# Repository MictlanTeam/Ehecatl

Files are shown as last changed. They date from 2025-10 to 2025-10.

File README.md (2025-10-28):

# EHECATL - Line Follower Racing Robot





**EHECATL** (pronunciado "Ehécatl") es un robot seguidor de línea diseñado para competencias de racing. Su nombre proviene del dios azteca del viento, representando su característica principal: un sistema de succión mediante turbina para generar efecto ground y aumentar la tracción en curvas a alta velocidad.

## 🏆 Características Principales

### Hardware
- **Microcontrolador**: ESP32-S3-Zero
- **Sensores**: Array de 16 sensores IR con multiplexadores duales
- **Motores**: 2 motores DC con drivers RZ7886
- **Turbina**: Sistema de succión con ESC brushless (efecto ground)
- **Control**: Botón físico, señal externa de start, y comandos serial

### Software
- **Control PID**: Controlador proporcional-derivativo ajustable
- **Pre-inicio Inteligente**: Estabilización y activación de turbina antes del arranque
- **Aceleración Adaptativa**: Velocidad mínima de 20% para arranques rápidos
- **Protocolo ESC**: Control de turbina a 50Hz (protocolo servo estándar)
- **Lectura Simétrica**: Sensores leídos desde el centro hacia extremos
- **Calibración Automática**: Auto-calibración con umbral adaptativo

## 🛠️ Especificaciones Técnicas

### Mapa de Pines

| Componente | Pin | Tipo | Descripción |
|---|-----|---|---|
| **Motores** |
| Motor Izq A | 1 | PWM | Control motor izquierdo |
| Motor Izq B | 4 | PWM | Control motor izquierdo |
| Motor Der A | 9 | PWM | Control motor derecho |
| Motor Der B | 2 | PWM | Control motor derecho |
| **Sensores** |
| MUX_A | 3 | Digital Out | Control multiplexador (LSB) |
| MUX_B | 11 | Digital Out | Control multiplexador |
| MUX_C | 10 | Digital Out | Control multiplexador (MSB) |
| Sensores 1-8 | 8 | Analog In | Lectura multiplexador 1 |
| Sensores 9-16 | 7 | Analog In | Lectura multiplexador 2 |
| **Utilidades** |
| LED | 5 | Digital Out | LED de estado |
| Botón | 13 | Digital In | Botón con pull-up |
| Start Signal | 6 | Digital In | Señal de inicio externa |
| Turbina | 12 | PWM (ESC) | Control turbina/succión |

### Configuraciones PWM

#### Motores
- **Frecuencia**: 5 kHz
- **Resolución**: 10 bits (0-1023)
- **Canales**: 0-3

#### Turbina (ESC)
- **Frecuencia**: 50 Hz (protocolo servo)
- **Resolución**: 11 bits
- **Rango**: 102-204 (1000μs-2000μs)
- **Canal**: 4

### Parámetros PID

```cpp
KP = 0.2    // Ganancia proporcional
KD = 0.80   // Ganancia derivativa
```

### Tiempos de Control

- **Loop de control**: 1000 μs (1 kHz)
- **Timeout pérdida de línea**: 250 ms
- **Calibración sensores**: 3000 ms
- **Tiempo máximo de prueba**: 30000 ms

## ⚙️ Configuración

### Configuración de Flash (platformio.ini)

```ini
[env:esp32-s3-zero]
platform = espressif32
board = esp32-s3-devkitc-1
framework = arduino
board_build.mcu = esp32s3
board_build.f_cpu = 240000000L
board_build.flash_mode = qio
board_upload.flash_size = 4MB
board_build.arduino.memory_type = qio_opi
board_build.psram_type = opi
board_build.partitions = default.csv
monitor_speed = 115200
upload_speed = 921600
```

### Ajuste de Parámetros

Los parámetros principales se pueden ajustar en:

- **`control.h`**: Constantes PID, tiempos de control
- **`motors.h`**: Configuración PWM de motores y turbina
- **`sensors.h`**: Configuración de sensores

## 📱 Uso Básico

### Inicio del Robot

1. **Encendido**: Conectar alimentación
2. **Inicialización**: Esperar 2 segundos (ESC de turbina)
3. **Calibración**: Presionar botón → Mover robot sobre línea 3 segundos
4. **Listo**: LED indica que está listo para iniciar

### Modos de Inicio

El robot puede iniciarse de 3 formas:

1. **Botón Largo (>1s)**:
   - Presionar y mantener botón
   - Cuenta regresiva de 3 segundos
   - Último segundo: pre-inicio con turbina al 85%
   - ¡GO!

2. **Señal Externa (Pin 6)**:
   - Compatible con sistemas de competencia
   - Inicio inmediato al detectar HIGH en pin 6

3. **Comando Serial (`s`)**:
   - Enviar comando `s` por monitor serial
   - Cuenta regresiva de 3 segundos
   - Inicio automático

### Comandos Serial

| Comando | Función | Ejemplo |
|---|---|---|
| `s` | Iniciar carrera | - |
| `x` | Detener carrera | - |
| `r` | Mostrar sensores RAW | - |
| `c` | Mostrar sensores calibrados | - |
| `v[num]` | Cambiar velocidad base (0-100%) | `v40` |
| `a[num]` | Cambiar aceleración (0-100%) | `a70` |
| `f[num]` | Cambiar velocidad turbina (0-100%) | `f90` |
| `cal` | Re-calibrar sensores | - |

## 📊 Rendimiento

## 📝 Licencia

Este proyecto está bajo la Licencia MIT. Ver archivo `LICENSE` para más detalles.

## 🔗 Enlaces Útiles

- [Documentación ESP32-S3](https://docs.espressif.com/projects/esp-idf/en/latest/esp32s3/)
- [PlatformIO Docs](https://docs.platformio.org/)
- [ESP32-S3-Zero](https://www.waveshare.com/wiki/ESP32-S3-Zero)

---

**EHECATL** - El viento que domina la pista 💨🏎️

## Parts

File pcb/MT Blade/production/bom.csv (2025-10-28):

Designator | Footprint | Quantity | Value | LCSC Part #
AUX_FLEX1, FLEX_MORRO1 | TE_0-1734839-7_1x07-1MP_P0.5mm_Horizontal | 2 | Conn_01x07 | C388693
C1, C3 | 0805 | 2 | 10uF | C380331
C2, C4 | 0805 | 2 | 0.1uF | C2847428
MUX1, MUX2 | MUX_CD4051B | 2 | CD4051B | C3007951
R1, R10, R13, R16, R19, R22, R4, R7 | 0805 | 8 | 45 | C3017827
R11, R12, R14, R15, R17, R18, R2, R20, R21, R23, R24, R3, R5, R6, R8, R9 | 0805 | 16 | 10k | C17414
S1, S10, S11, S12, S13, S14, S15, S16, S2, S3, S4, S5, S6, S7, S8, S9 | ITR8307_SMD | 16 | ~ | C81632

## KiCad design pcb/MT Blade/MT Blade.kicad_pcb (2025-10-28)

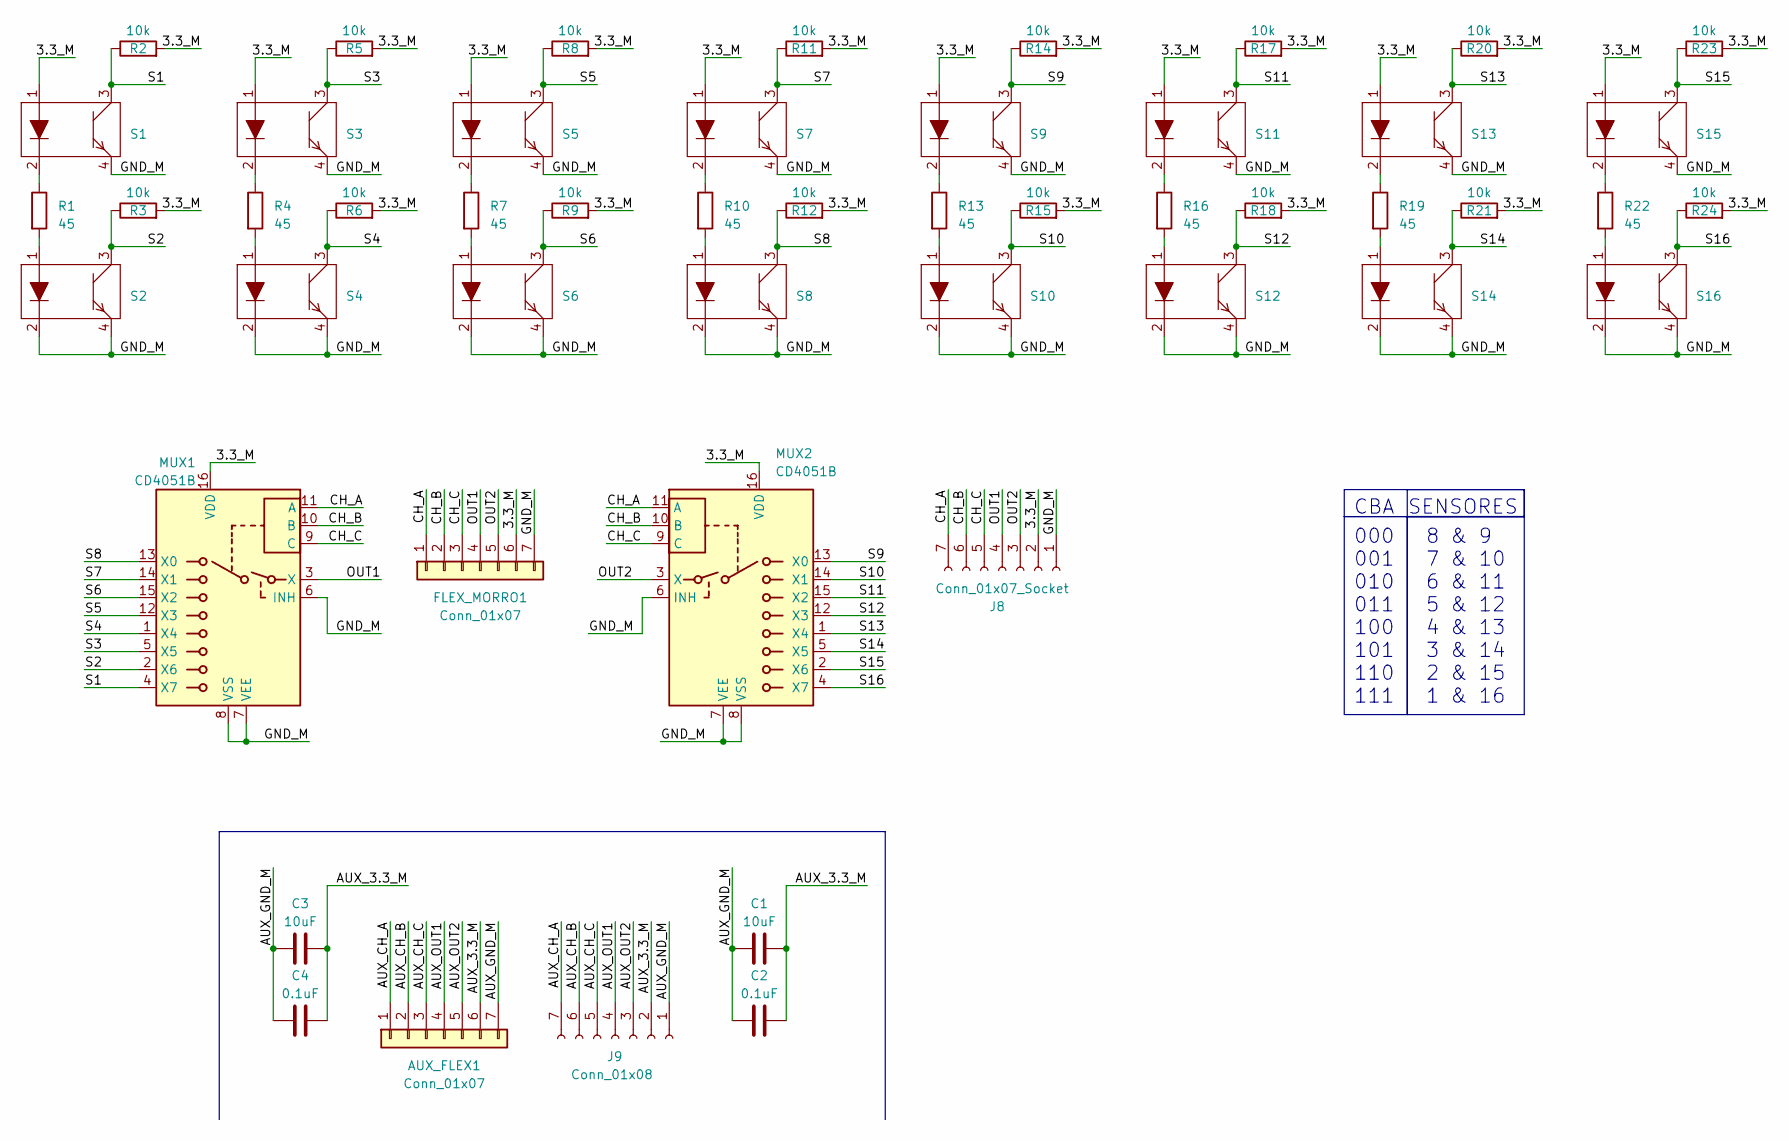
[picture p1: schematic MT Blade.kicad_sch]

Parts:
AUX_FLEX1: Conn_01x07; TE_0-1734839-7_1x07-1MP_P0.5mm_Horizontal; LCSC Part # C388693
C1, C3: 10uF; C_0805_2012Metric_Pad1.18x1.45mm_HandSolder; LCSC Part # C380331
C2, C4: 0.1uF; C_0805_2012Metric_Pad1.18x1.45mm_HandSolder; LCSC Part # C2847428
FLEX_MORRO1: Conn_01x07; TE_0-1734839-7_1x07-1MP_P0.5mm_Horizontal; LCSC Part # C388693
J8: Conn_01x07_Socket; PinHeader_1x07_P2.54mm_Vertical
J9: Conn_01x08; PinHeader_1x07_P2.54mm_Vertical
MUX1, MUX2: CD4051B; MUX_CD4051B; LCSC Part # C3007951
R1, R4, R7, R10, R13, R16, R19, R22: 45; R_0805_2012Metric_Pad1.20x1.40mm_HandSolder; LCSC Part # C3017827
R2, R3, R5, R6, R8, R9, R11, R12, R14, R15, R17, R18, R20, R21, R23, R24: 10k; R_0805_2012Metric_Pad1.20x1.40mm_HandSolder; LCSC Part # C17414
S1, S2, S3, S4, S5, S6, S7, S8, S9, S10, S11, S12, S13, S14, S15, S16: ITR8307_SMD; LCSC Part # C81632

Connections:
/3.3_M: FLEX_MORRO1.6, J8.2, MUX1.16 (VDD), MUX2.16 (VDD), R2.2, R3.2, R5.2, R6.2, R8.2, R9.2, R11.2, R12.2, R14.2, R15.2, R17.2, R18.2, R20.2, R21.2, R23.2, R24.2, S1.1, S3.1, S5.1, S7.1, S9.1, S11.1, S13.1, S15.1
/AUX_3.3_M: AUX_FLEX1.6, C1.1, C2.1, C3.1, C4.1, J9.2
/AUX_CH_A: AUX_FLEX1.1, J9.7
/AUX_CH_B: AUX_FLEX1.2, J9.6
/AUX_CH_C: AUX_FLEX1.3, J9.5
/AUX_GND_M: AUX_FLEX1.7, C1.2, C2.2, C3.2, C4.2, J9.1
/AUX_OUT1: AUX_FLEX1.4, J9.4
/AUX_OUT2: AUX_FLEX1.5, J9.3
/CH_A: FLEX_MORRO1.1, J8.7, MUX1.11 (A), MUX2.11 (A)
/CH_B: FLEX_MORRO1.2, J8.6, MUX1.10 (B), MUX2.10 (B)
/CH_C: FLEX_MORRO1.3, J8.5, MUX1.9 (C), MUX2.9 (C)
/GND_M: FLEX_MORRO1.7, J8.1, MUX1.6 (INH), MUX1.7 (VEE), MUX1.8 (VSS), MUX2.6 (INH), MUX2.7 (VEE), MUX2.8 (VSS), S1.4, S2.2, S2.4, S3.4, S4.2, S4.4, S5.4, S6.2, S6.4, S7.4, S8.2, S8.4, S9.4, S10.2, S10.4, S11.4, S12.2, S12.4, S13.4, S14.2, S14.4, S15.4, S16.2, S16.4
/OUT1: FLEX_MORRO1.4, J8.4, MUX1.3 (X)
/OUT2: FLEX_MORRO1.5, J8.3, MUX2.3 (X)
/S1: MUX1.4 (X7), R2.1, S1.3
/S2: MUX1.2 (X6), R3.1, S2.3
/S3: MUX1.5 (X5), R5.1, S3.3
/S4: MUX1.1 (X4), R6.1, S4.3
/S5: MUX1.12 (X3), R8.1, S5.3
/S6: MUX1.15 (X2), R9.1, S6.3
/S7: MUX1.14 (X1), R11.1, S7.3
/S8: MUX1.13 (X0), R12.1, S8.3
/S9: MUX2.13 (X0), R14.1, S9.3
/S10: MUX2.14 (X1), R15.1, S10.3
/S11: MUX2.15 (X2), R17.1, S11.3
/S12: MUX2.12 (X3), R18.1, S12.3
/S13: MUX2.1 (X4), R20.1, S13.3
/S14: MUX2.5 (X5), R21.1, S14.3
/S15: MUX2.2 (X6), R23.1, S15.3
/S16: MUX2.4 (X7), R24.1, S16.3
unnamed: R1.1, S1.2
unnamed: R1.2, S2.1
unnamed: R4.1, S3.2
unnamed: R4.2, S4.1
unnamed: R7.1, S5.2
unnamed: R7.2, S6.1
unnamed: R10.1, S7.2
unnamed: R10.2, S8.1
unnamed: R13.1, S9.2
unnamed: R13.2, S10.1
unnamed: R16.1, S11.2
unnamed: R16.2, S12.1
unnamed: R19.1, S13.2
unnamed: R19.2, S14.1
unnamed: R22.1, S15.2
unnamed: R22.2, S16.1

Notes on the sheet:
CBA
SENSORES
8 & 9 7 & 10 6 & 11 5 & 12 4 & 13 3 & 14 2 & 15 1 & 16
000 001 010 011 100 101 110 111

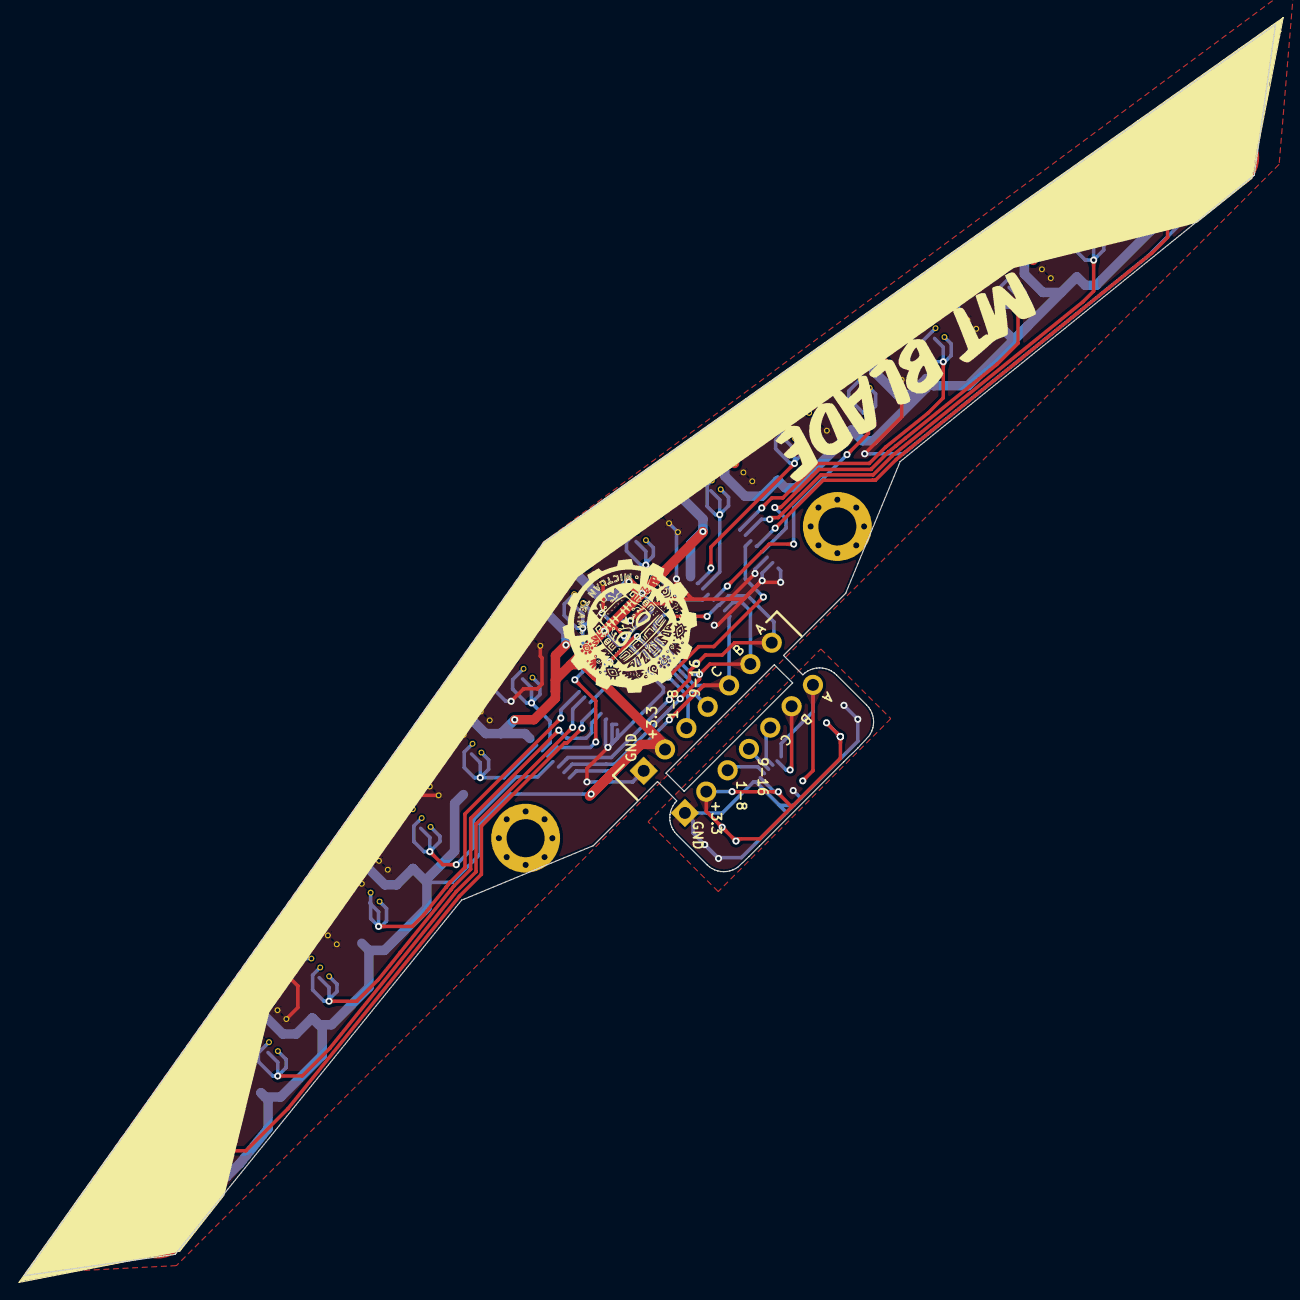
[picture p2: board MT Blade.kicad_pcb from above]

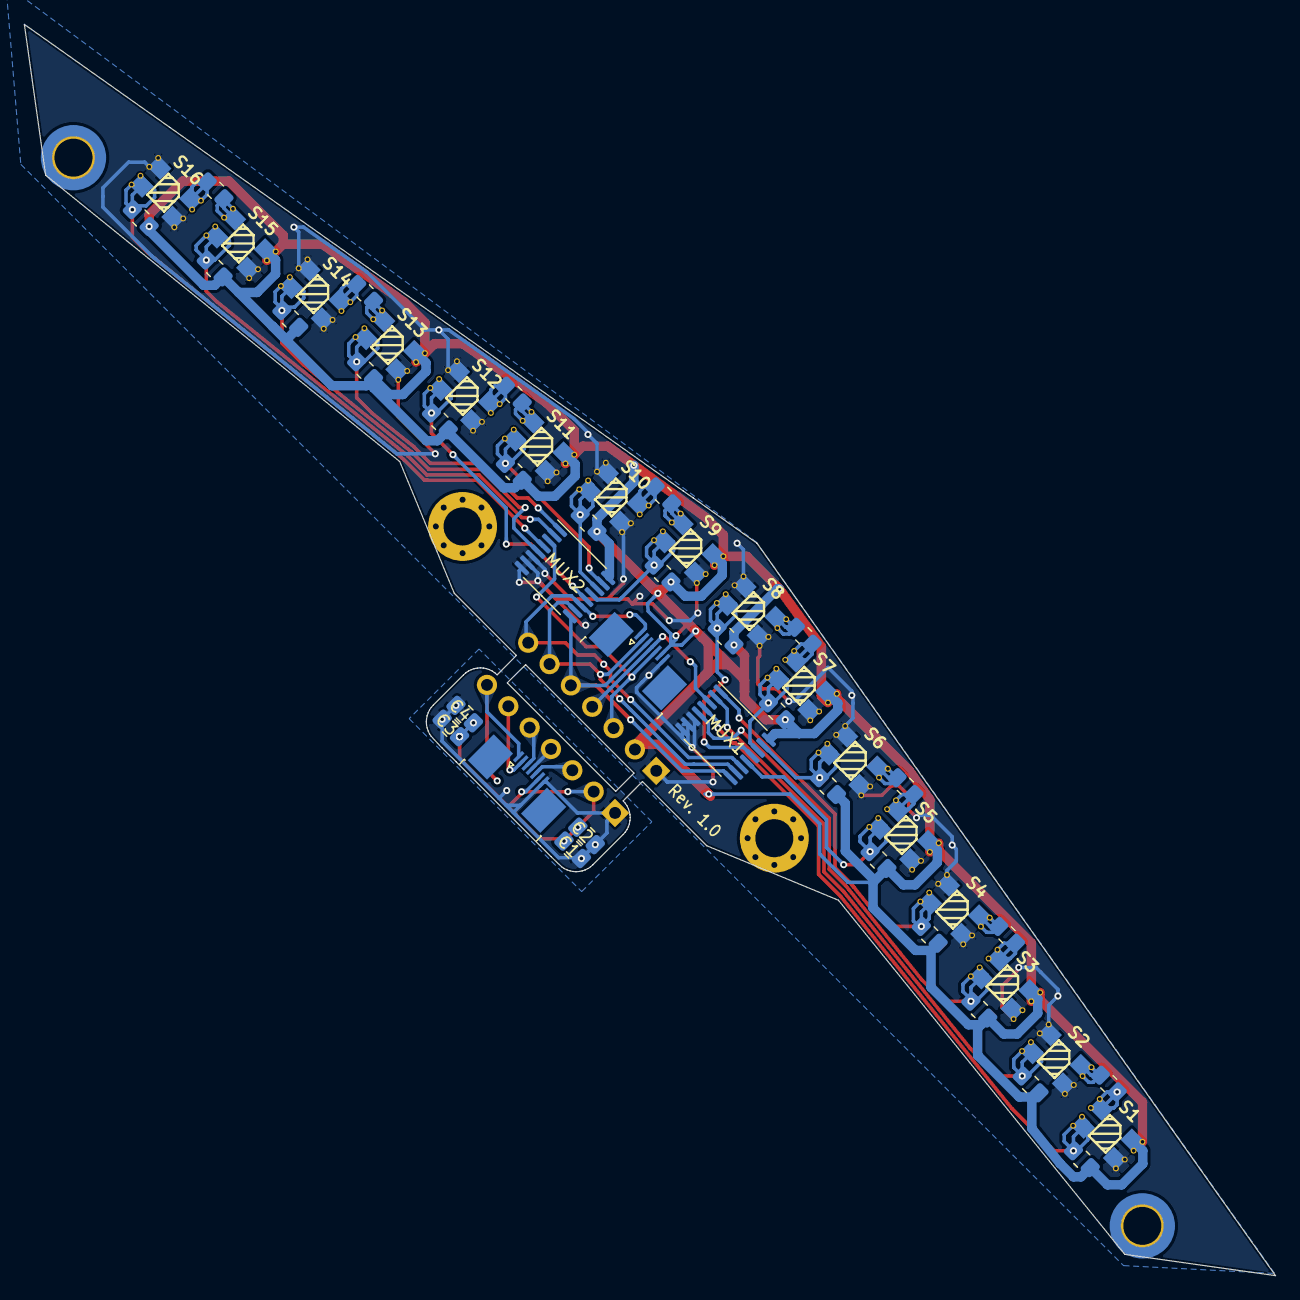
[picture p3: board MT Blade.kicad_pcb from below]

Board: 2 copper layers, 105.3 x 105.3 mm, 51 parts (49 on the bottom side), 46 nets.

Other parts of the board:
G: LOGO; MT_Silkscreen 10mm

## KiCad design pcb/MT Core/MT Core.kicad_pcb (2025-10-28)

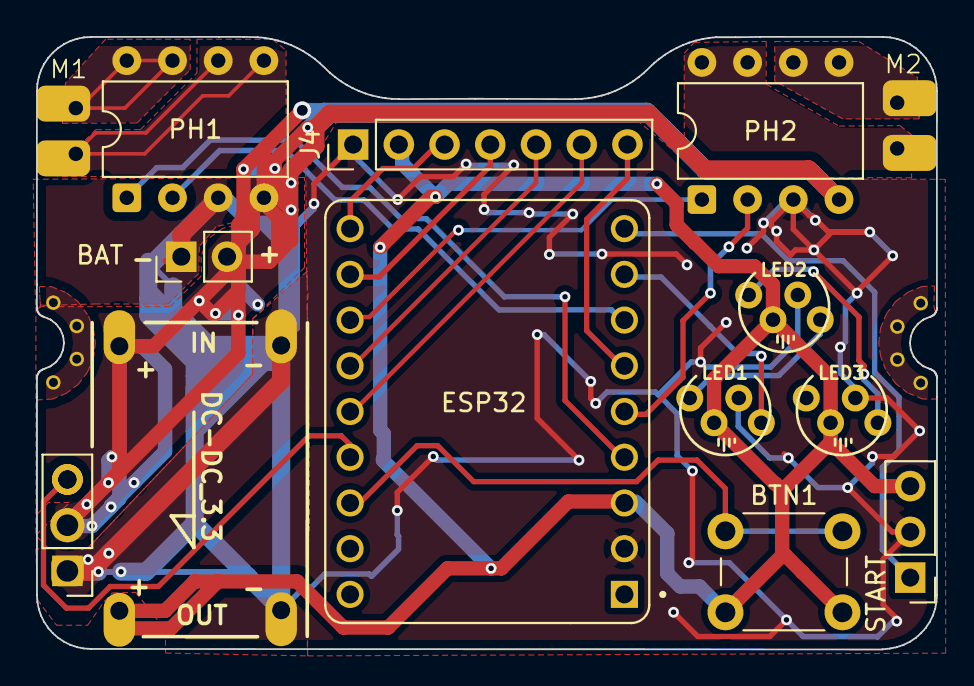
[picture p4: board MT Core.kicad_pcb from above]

Board: 2 copper layers, 50.0 x 34.0 mm, 15 parts (0 on the bottom side), 22 nets.

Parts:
BAT: Conn_01x02_Socket; PinHeader_1x02_P2.54mm_Vertical
BTN1: SW_PUSH_6mm_H4.3mm
DC-DC_3.3: DC-DC_3.3 CN3903
ESP32: ESP32-S3-ZERO
J1: Conn_01x03_Socket; PinHeader_1x03_P2.54mm_Vertical
J4: Conn_01x07_Socket; PinHeader_1x07_P2.54mm_Vertical
LED1, LED2, LED3: LED_D5.0mm-4_RGB_Staggered_Pins
M1, M2: Conn_01x02_Socket; motor_pads
PH1, PH2: DIP-8_W7.62mm
START: Conn_01x03_Socket; PinHeader_1x03_P2.54mm_Vertical
SUCC: Conn_01x03_Socket; PinHeader_1x03_P2.54mm_Vertical

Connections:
+3.3V: BTN1.2, DC-DC_3.3.3 (OUT+), ESP32.3V3 (3V3(OUT)), J4.2, LED1.2 (VDD), LED2.2 (VDD), LED3.2 (VDD), START.3
/BATT: BAT.2, DC-DC_3.3.1 (IN+), J1.2, PH1.4 (VCC), PH2.4 (VCC), SUCC.2
/BTN: BTN1.1, ESP32.13 (GP13)
/LEDS: ESP32.5 (GP5), LED1.4 (DIN)
/PIN0: ESP32.7 (GP7), J4.3
/PIN1: ESP32.8 (GP8), J4.4
/PIN3: ESP32.10 (GP10), J4.5
/PIN4: ESP32.11 (GP11), J4.6
/PIN9: ESP32.3 (GP3), J4.7
/PWM_M1A: ESP32.1 (GP1), PH1.1 (S1)
/PWM_M1B: ESP32.4 (GP4), PH1.2 (S2)
/PWM_M2A: ESP32.9 (GP9), PH2.1 (S1)
/PWM_M2B: ESP32.2 (GP2), PH2.2 (S2)
/START: ESP32.6 (GP6), START.1
/SUCC: ESP32.12 (GP12), J1.3, SUCC.3
GND: BAT.1, DC-DC_3.3.2 (IN-), DC-DC_3.3.4 (OUT-), ESP32.GND, J1.1, J4.1, LED1.3 (GND), LED2.3 (GND), LED3.3 (GND), PH1.3 (GND), PH2.3 (GND), START.2, SUCC.1
unnamed: LED1.1 (DOUT), LED2.4 (DIN)
unnamed: LED2.1 (DOUT), LED3.4 (DIN)
unnamed: M1.1, PH1.5 (M+), PH1.6 (M+)
unnamed: M1.2, PH1.7 (M-), PH1.8 (M-)
unnamed: M2.1, PH2.5 (M+), PH2.6 (M+)
unnamed: M2.2, PH2.7 (M-), PH2.8 (M-)

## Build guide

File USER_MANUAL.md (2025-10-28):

# 📖 Manual de Usuario - EHECATL

## Guía de Operación del Robot Seguidor de Línea

---

## 🚦 Inicio Rápido

### 1. Primera Vez - Configuración Inicial

#### Paso 1: Conexión
1. Conecta la batería al robot
2. Espera 2 segundos (oirás un beep del ESC de la turbina)
3. El LED parpadeará indicando que está listo para calibrar

#### Paso 2: Calibración de Sensores
1. **Presiona el botón** del robot
2. **Mueve el robot lentamente** sobre la línea durante 3 segundos
   - Pasa por línea negra
   - Pasa por fondo blanco
   - Repite varias veces
3. Cuando termine:
   - ✅ LED se encenderá brevemente si calibración OK
   - ❌ LED parpadeará rápido si falló (repetir calibración)

> **💡 Consejo**: Mueve el robot lentamente y asegúrate de que todos los sensores pasen por la línea

---

## 🏁 Usar el Robot

### Método 1: Botón Físico (Recomendado)

1. **Posiciona** el robot en la pista (centrado en la línea)
2. **Presiona y mantén** el botón por más de 1 segundo
3. **Suelta** el botón cuando el LED parpadee rápido
4. **Cuenta regresiva automática**:
   ```
   3... (LED parpadea)
   2... (LED parpadea)
   1... (LED encendido fijo - turbina al 85%)
   ¡GO! (Robot arranca)
   ```

5. El robot seguirá la línea automáticamente
6. Se detendrá solo después de 30 segundos

### Método 2: Señal Externa (Para Competencias)

1. Conecta sistema de inicio al **Pin 6**
2. Cuando el pin reciba señal HIGH, el robot arranca inmediatamente
3. No hay cuenta regresiva en este modo

### Método 3: Comando Serial (Para Pruebas)

1. Abre el monitor serial (115200 baud)
2. Escribe: `s` y presiona Enter
3. Cuenta regresiva de 3 segundos
4. Robot arranca automáticamente

---

## 🛑 Detener el Robot

### Durante la Carrera:

- **Botón**: Presiona brevemente el botón
- **Serial**: Envía comando `x`
- **Automático**: Robot se detiene si pierde la línea por más de 250ms

---

## ⚙️ Ajustar Configuración

### Abrir Monitor Serial

**En PlatformIO**:
- Click en icono "Monitor Serial"
- O presiona `Ctrl+Alt+M`

**Velocidad**: 115200 baud

### Comandos Disponibles

#### Velocidad del Robot
```
v30   → Velocidad base 30%
v50   → Velocidad base 50%
v80   → Velocidad base 80%
```

#### Aceleración
```
a40   → Aceleración lenta
a60   → Aceleración media (recomendada)
a80   → Aceleración rápida
```

#### Turbina
```
f0    → Turbina apagada
f50   → Turbina 50%
f80   → Turbina 80% (recomendada)
f100  → Turbina máxima
```

#### Otros Comandos
```
s     → Iniciar carrera
x     → Detener carrera
r     → Ver valores RAW de sensores
c     → Ver sensores calibrados (0 o 1)
cal   → Re-calibrar sensores
```

---

## 🎯 Configuraciones Recomendadas

### Para Empezar (Pista Desconocida)
```
v30    (velocidad baja)
a60    (aceleración media)
f60    (turbina media)
```

### Pista con Curvas Suaves
```
v50    (velocidad media)
a70    (aceleración alta)
f80    (turbina alta)
```

### Pista Rápida con Pocas Curvas
```
v70    (velocidad alta)
a80    (aceleración muy alta)
f80    (turbina alta)
```

### Modo Máximo (Solo Pistas Conocidas)
```
v100   (velocidad máxima)
a90    (aceleración máxima)
f100   (turbina máxima)
```

---

## 🔧 Mantenimiento

### Antes de Cada Carrera

1. ✅ **Verificar batería cargada**
2. ✅ **Limpiar sensores** (paño seco suave)
3. ✅ **Verificar ruedas** (no hay objetos pegados)
4. ✅ **Probar turbina** (debe girar suave al encender)
5. ✅ **Calibrar sensores** si cambió la pista

### Después de Cada Carrera

1. ✅ **Desconectar batería**
2. ✅ **Limpiar robot** (quitar polvo)
3. ✅ **Revisar tornillos** (que estén ajustados)

### Limpieza de Sensores

**Frecuencia**: Cada 5 carreras o si detectas problemas

**Método**:
1. Apaga el robot
2. Usa paño de microfibra seco
3. Limpia suavemente cada sensor
4. NO uses líquidos
5. NO presiones fuerte

---

## 🐛 Solución de Problemas Comunes

### Problema: Robot no enciende

**Posibles causas**:
- ❌ Batería descargada
- ❌ Conexión suelta

**Solución**:
1. Verifica voltaje de batería (mínimo 7.4V)
2. Revisa conexiones de alimentación

---

### Problema: Robot pierde la línea constantemente

**Posibles causas**:
- ❌ Sensores sucios
- ❌ Mala calibración
- ❌ Velocidad muy alta

**Solución**:
1. Limpia sensores con paño seco
2. Re-calibra: Comando `cal`
3. Reduce velocidad: `v30`
4. Verifica en serial: Comando `r` para ver valores

---

### Problema: Turbina no funciona

**Posibles causas**:
- ❌ ESC no inicializado
- ❌ Turbina configurada en 0%

**Solución**:
1. Espera 2-3 segundos al encender (beep del ESC)
2. Configura turbina: `f80`
3. Verifica conexión del ESC

---

### Problema: Motores no responden

**Posibles causas**:
- ❌ Robot no está en modo carrera
- ❌ Conexión suelta
- ❌ Driver sobrecalentado

**Solución**:
1. Inicia carrera: Botón largo o comando `s`
2. Verifica conexiones de motores
3. Si drivers están calientes, espera 5 minutos

---

### Problema: Robot gira en círculos

**Posibles causas**:
- ❌ Mal montaje de ruedas
- ❌ Motores invertidos
- ❌ Calibración incorrecta

**Solución**:
1. Verifica que ambas ruedas giren bien
2. Re-calibra sensores
3. Prueba en pista simple primero

---

### Problema: Sensores no detectan línea

**Verificación**:
1. Comando `r` en serial
2. Valores deben cambiar al pasar sobre línea:
   - Fondo blanco: ~3000-4000
   - Línea negra: ~100-500
3. Si no cambian:
   - Sensores muy altos/bajos de la pista
   - Sensores sucios
   - Luz ambiental muy intensa

**Solución**:
1. Ajusta altura del robot (3-5mm ideal)
2. Limpia sensores
3. Evita luz solar directa
4. Re-calibra

---

## 📊 Interpretación de Sensores

### Ver Estado de Sensores

Comando `c` muestra sensores calibrados:
```
CAL: 0 0 0 0 0 1 1 1 1 0 0 0 0 0 0 0
     ◄────────────────────────────►
     Izq                         Der
```

**Interpretación**:
- `1` = Sensor detecta línea (negro)
- `0` = Sensor detecta fondo (blanco)

**Ejemplos**:

```
Línea Centrada:
0 0 0 0 0 0 1 1 1 0 0 0 0 0 0 0
              ▲▲▲
           Centro perfecto
```

```
Línea a la Derecha:
0 0 0 0 0 0 0 0 0 0 1 1 1 0 0 0
                        ▲▲▲
                  Debe girar derecha
```

```
Línea a la Izquierda:
0 0 1 1 1 0 0 0 0 0 0 0 0 0 0 0
      ▲▲▲
  Debe girar izquierda
```

```
Línea Perdida:
0 0 0 0 0 0 0 0 0 0 0 0 0 0 0 0
          ⚠️ ALERTA ⚠️
```

---

## 💾 Guardar Configuración

El robot **NO guarda** configuraciones automáticamente.

Para guardar tus configuraciones preferidas:

### Opción 1: Modificar Código
En `main.cpp` líneas 70-72:
```cpp
set_base_speed(50);        // Cambia 50 por tu velocidad
set_base_accel_speed(70);  // Cambia 70 por tu aceleración
set_base_fan_speed(80);    // Cambia 80 por tu turbina
```

### Opción 2: Crear Script
Crea archivo `config.txt` con tus comandos:
```
v50
a70
f80
```
Y envíalos cada vez que enciendas

---

## 🔋 Batería

### Especificaciones
- **Voltaje**: 7.4V - 11.1V (2S - 3S LiPo)
- **Capacidad recomendada**: 1000-2000 mAh
- **Descarga**: 20C o superior

### Duración Estimada
- **Sin turbina**: ~15-20 minutos
- **Con turbina 50%**: ~8-12 minutos
- **Con turbina 100%**: ~5-8 minutos

### Indicadores de Batería Baja
- Robot pierde potencia en curvas
- Turbina hace ruidos extraños
- Velocidad máxima reducida

**⚠️ IMPORTANTE**:
- Nunca descargues LiPo por debajo de 3.0V por celda
- Usa alarma de voltaje o cargador con balance

---

## 🎓 Consejos de Competencia

### Antes de la Competencia

1. **Practica en pista similar**
2. **Calibra con la pista real** de competencia
3. **Prueba diferentes configuraciones**
4. **Anota tus mejores configuraciones**
5. **Carga batería completa**
6. **Lleva baterías de repuesto**

### Durante Clasificación

1. **Primera vuelta: Conservador** (v40, a50, f60)
2. **Observa el circuito** mientras el robot corre
3. **Identifica curvas difíciles**
4. **Ajusta configuración** basado en observación

### Para la Final

1. **Usa configuración probada**
2. **No cambies a último momento**
3. **Calibra 5 minutos antes de tu turno**
4. **Verifica batería cargada**

---

## 📈 Mejorando Tiempos

### Progresión Sugerida

**Semana 1**: Conocer el robot
```
v30, a50, f50
Objetivo: Completar pista sin salirse
```

**Semana 2**: Aumentar confianza
```
v50, a60, f70
Objetivo: Completar pista consistentemente
```

**Semana 3**: Velocidad
```
v70, a70, f80
Objetivo: Reducir tiempo en 30%
```

**Semana 4+**: Optimización
```
v80-100, a80-90, f80-100
Objetivo: Tiempo mínimo consistente
```

---

## ✅ Checklist Pre-Carrera

Antes de cada carrera, verifica:

- [ ] Batería cargada (>7.4V)
- [ ] Sensores limpios
- [ ] Turbina funciona (oyes el beep al encender)
- [ ] LED responde al presionar botón
- [ ] Calibración reciente (<10 minutos)
- [ ] Configuración cargada (v, a, f)
- [ ] Robot centrado en línea de inicio
- [ ] Ruedas limpias (sin objetos)
- [ ] Tornillos ajustados

---

## 🎉 ¡Listo para Competir!

Ahora que conoces tu robot EHECATL, es momento de dominarlo en la pista.

**Recuerda**:
- Empieza lento y aumenta velocidad gradualmente
- La calibración es CRÍTICA
- Cada pista es diferente
- Práctica hace al maestro

---

**¡Buena suerte en tus carreras!** 🏁💨

*EHECATL - El viento que domina la pista*

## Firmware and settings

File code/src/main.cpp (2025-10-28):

#include <Arduino.h>
#include <pinout.h>
#include <sensors.h>
#include <motors.h>
#include <control.h>
#include <utils.h>

/**
 * @brief Configuración del robot
 *
 */
#define TEST_DURATION_MS 30000   // Tiempo máximo de prueba: 30 segundos
#define START_DELAY_MS 3000      // Delay antes de iniciar: 3 segundos

void setup() {
  Serial.begin(115200);
  delay(1000);

  Serial.println("==============================================");
  Serial.println("  EHECATL - Line Follower Robot");
  Serial.println("  Basado en PX-01 Basic");
  Serial.println("==============================================");
  Serial.println();

  // Inicializar componentes
  Serial.println("Inicializando componentes...");
  init_utils();
  init_sensors();
  init_motors();

  Serial.println();
  Serial.println("==============================================");
  Serial.println("  CONFIGURACION DE PINES");
  Serial.println("==============================================");
  Serial.println("Motor Izquierdo:");
  Serial.println("  PWMA: Pin 1");
  Serial.println("  PWMB: Pin 4");
  Serial.println();
  Serial.println("Motor Derecho:");
  Serial.println("  PWMA: Pin 9");
  Serial.println("  PWMB: Pin 2");
  Serial.println();
  Serial.println("Sensores (Multiplexadores):");
  Serial.println("  MUX_A: Pin 3");
  Serial.println("  MUX_B: Pin 11");
  Serial.println("  MUX_C: Pin 10");
  Serial.println("  Lectura 1-8:  Pin 8");
  Serial.println("  Lectura 9-16: Pin 7");
  Serial.println();
  Serial.println("Utilidades:");
  Serial.println("  LED:     Pin 5");
  Serial.println("  Boton:   Pin 13");
  Serial.println("  Start:   Pin 6");
  Serial.println("  Turbina: Pin 12");
  Serial.println("==============================================");
  Serial.println();

  // LED parpadeando indicando calibración
  Serial.println("Presiona el boton para calibrar sensores...");
  while (get_btn_state() != BTN_PRESSED && get_btn_state() != BTN_LONG_PRESSED) {
    blink_led(500);
  }
  set_led(false);
  delay(500);

  // Calibrar sensores
  calibrate_sensors();

  // Configurar velocidades
  set_base_speed(30);        // Velocidad base: 30%
  set_base_accel_speed(60);  // Aceleración: 60%
  set_base_fan_speed(80);    // Turbina: 80%

  Serial.println("Sistema listo!");
  Serial.println();
  Serial.println("==============================================");
  Serial.println("  MODOS DE INICIO");
  Serial.println("==============================================");
  Serial.println("  1. Presion LARGA del boton (>1s)");
  Serial.println("  2. Senal de START (Pin 6)");
  Serial.println("  3. Comando serial: s");
  Serial.println();
  Serial.println("  OTROS COMANDOS:");
  Serial.println("  x - Detener carrera");
  Serial.println("  r - Mostrar sensores RAW");
  Serial.println("  c - Mostrar sensores calibrados");
  Serial.println("  v[num] - Cambiar velocidad base (ej: v40)");
  Serial.println("  a[num] - Cambiar aceleracion (ej: a70)");
  Serial.println("  f[num] - Cambiar velocidad turbina (ej: f90)");
  Serial.println("  cal - Re-calibrar sensores");
  Serial.println("==============================================");
  Serial.println();

  // LED indicando listo para iniciar
  set_led(true);
  delay(500);
  set_led(false);
}

void loop() {
  // Verificar si NO está en carrera
  if (!is_race_started()) {

    // Leer estado del botón
    BTN_STATES btn_state = get_btn_state();

    // Mientras el botón está presionado, parpadear LED rápido
    if (btn_state == BTN_PRESSING && get_btn_pressing_ms() >= 250) {
      blink_led(125);
    }

    // Si se soltó el botón después de presión larga, iniciar carrera
    if (btn_state == BTN_LONG_PRESSED) {
      Serial.println();
      Serial.println("Boton LARGO detectado!");
      set_led(true);

      // Cuenta regresiva con parpadeos (3 segundos)
      Serial.println("Iniciando en:");
      long starting_ms = millis();
      long countdown_duration = 3000;  // 3 segundos

      while (millis() < (starting_ms + countdown_duration)) {
        long elapsed = millis() - starting_ms;

        // Primeros 2 segundos: parpadeo lento
        if (elapsed < countdown_duration - 1000) {
          // Mostrar cuenta regresiva
          int seconds_remaining = 3 - (elapsed / 1000);
          static int last_second = -1;
          if (seconds_remaining != last_second) {
            Serial.print("  ");
            Serial.print(seconds_remaining);
            Serial.println("...");
            last_second = seconds_remaining;
          }

          // Parpadeo cada 500ms
          if ((elapsed % 1000) < 500) {
            set_led(true);
          } else {
            set_led(false);
          }

        } else {
          // Último segundo: PRE-INICIO INTELIGENTE
          set_led(true);
          set_race_starting(true);

          // Activar turbina al 85% para preparar succión
          if (get_base_fan_speed() > 0) {
            set_fan_speed(get_base_fan_speed() * 0.85f);
            Serial.println("  Pre-inicio: Turbina activada al 85%");
          }

          // Ejecutar control PID sin avanzar (mantiene centrado)
          initial_control_loop();
        }
      }

      Serial.println("  GO!");
      set_led(false);
      set_race_started(true);
    }

    // Verificar señal de START externa
    if (get_start_signal()) {
      Serial.println();
      Serial.println("Senal de START detectada!");
      delay(100);  // Pequeño delay para estabilizar
      set_race_started(true);
    }

    // Procesar comandos del serial
    if (Serial.available() > 0) {
      String command = Serial.readStringUntil('\n');
      command.trim();

      if (command == "s") {
        // Iniciar carrera con delay
        Serial.println();
        Serial.println("Iniciando en 3 segundos...");
        for (int i = 3; i > 0; i--) {
          Serial.print(i);
          Serial.println("...");
          delay(1000);
        }
        set_race_started(true);

      } else if (command == "r") {
        // Mostrar sensores RAW
        print_sensors_raw();

      } else if (command == "c") {
        // Mostrar sensores calibrados
        print_sensors_calibrated();

      } else if (command.startsWith("v")) {
        // Cambiar velocidad base
        int speed = command.substring(1).toInt();
        set_base_speed(speed);

      } else if (command.startsWith("a")) {
        // Cambiar aceleración
        int accel = command.substring(1).toInt();
        set_base_accel_speed(accel);

      } else if (command.startsWith("f")) {
        // Cambiar velocidad turbina
        int fan = command.substring(1).toInt();
        set_base_fan_speed(fan);

      } else if (command == "cal") {
        // Re-calibrar sensores
        Serial.println("Re-calibrando sensores...");
        calibrate_sensors();

      } else if (command == "x") {
        // Este comando solo funciona durante la carrera
        Serial.println("El robot no esta en carrera");

      } else {
        Serial.println("Comando no reconocido");
      }
    }

  } else {
    // EN CARRERA

    // Ejecutar bucle de control
    control_loop();

    // Verificar comando de detención por serial
    if (Serial.available() > 0) {
      String command = Serial.readStringUntil('\n');
      command.trim();
      if (command == "x") {
        Serial.println();
        Serial.println("Detencion manual solicitada");
        set_race_started(false);
      }
    }

    // Verificar botón para detener
    BTN_STATES btn_state = get_btn_state();
    if (btn_state == BTN_PRESSED || btn_state == BTN_LONG_PRESSED) {
      Serial.println();
      Serial.println("Boton presionado - Deteniendo");
      set_race_started(false);
    }

    // Detener después del tiempo máximo de prueba
    if (millis() - get_race_started_ms() >= TEST_DURATION_MS) {
      Serial.println();
      Serial.println("Tiempo de prueba completado");
      set_race_started(false);
    }
  }
}

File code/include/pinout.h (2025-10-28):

#ifndef PINOUT_H
#define PINOUT_H

/**
 * @brief Pin del LED de estado
 *
 */
#define LED_PIN 5

/**
 * @brief Pin del botón de inicio
 *
 */
#define BUTTON_PIN 13

/**
 * @brief Pin de la señal de start (entrada)
 *
 */
#define START_SIGNAL_PIN 6

/**
 * @brief Pin de control de la turbina/succión
 *
 */
#define FAN_PIN 12

/**
 * @brief Pines de control de multiplexadores (compartidos)
 *
 */
#define MUX_A 3
#define MUX_B 11
#define MUX_C 10

/**
 * @brief Pines de lectura de sensores
 *
 */
#define SENSOR_1_8 8    // Lee sensores 1-8
#define SENSOR_9_16 7   // Lee sensores 9-16

/**
 * @brief Pines del driver RZ7886 - Motor Izquierdo
 *
 */
#define MOTOR_LEFT_A 1
#define MOTOR_LEFT_B 4

/**
 * @brief Pines del driver RZ7886 - Motor Derecho
 *
 */
#define MOTOR_RIGHT_A 9
#define MOTOR_RIGHT_B 2

#endif // PINOUT_H

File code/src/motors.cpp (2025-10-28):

#include <motors.h>
#include <control.h>

/**
 * @brief Inicializa los motores configurando los canales PWM
 *
 */
void init_motors() {
  // Configuración de los canales PWM del Timer - Motores
  ledcSetup(PWM_MOTOR_LEFT_A, PWM_MOTORS_HZ, PWM_MOTORS_RESOLUTION);
  ledcSetup(PWM_MOTOR_LEFT_B, PWM_MOTORS_HZ, PWM_MOTORS_RESOLUTION);
  ledcSetup(PWM_MOTOR_RIGHT_A, PWM_MOTORS_HZ, PWM_MOTORS_RESOLUTION);
  ledcSetup(PWM_MOTOR_RIGHT_B, PWM_MOTORS_HZ, PWM_MOTORS_RESOLUTION);

  // Configuración del canal PWM para ESC de turbina (50Hz = protocolo servo)
  ledcSetup(PWM_FAN, PWM_FAN_HZ, PWM_FAN_RESOLUTION);

  // Asignación de los pines a los canales PWM
  ledcAttachPin(MOTOR_LEFT_A, PWM_MOTOR_LEFT_A);
  ledcAttachPin(MOTOR_LEFT_B, PWM_MOTOR_LEFT_B);
  ledcAttachPin(MOTOR_RIGHT_A, PWM_MOTOR_RIGHT_A);
  ledcAttachPin(MOTOR_RIGHT_B, PWM_MOTOR_RIGHT_B);
  ledcAttachPin(FAN_PIN, PWM_FAN);

  // Establece el valor inicial de los canales PWM
  ledcWrite(PWM_MOTOR_LEFT_A, PWM_MOTORS_MIN);
  ledcWrite(PWM_MOTOR_LEFT_B, PWM_MOTORS_MIN);
  ledcWrite(PWM_MOTOR_RIGHT_A, PWM_MOTORS_MIN);
  ledcWrite(PWM_MOTOR_RIGHT_B, PWM_MOTORS_MIN);
  ledcWrite(PWM_FAN, PWM_FAN_MIN);

  // Tiempo de espera para inicialización del ESC
  // El ESC necesita 2-3 segundos para calibrar
  // Este delay se puede quitar si ya se espera durante la calibración de sensores
  Serial.println("Inicializando ESC de turbina...");
  delay(2000);
  Serial.println("ESC listo");
}

/**
 * @brief Establece la velocidad de los motores
 * Motor Izquierdo: MOTOR_LEFT_A y MOTOR_LEFT_B
 * Motor Derecho: MOTOR_RIGHT_A y MOTOR_RIGHT_B
 *
 * Lógica del driver RZ7886:
 * - Para avanzar: A=HIGH, B=LOW con PWM en A
 * - Para retroceder: A=LOW, B=HIGH con PWM en B
 * - Para frenar: A=HIGH, B=HIGH
 *
 * @param velI Velocidad del motor izquierdo (-100 a 100%)
 * @param velD Velocidad del motor derecho (-100 a 100%)
 */
void set_motors_speed(float velI, float velD) {
  // Limitar velocidades
  velI = constrain(velI, -100, 100);
  velD = constrain(velD, -100, 100);

  // Solo permitir movimiento si está en carrera, pre-inicio, o recién detenido (freno gradual)
  bool motors_enabled = is_race_started() || is_race_starting() || (millis() - get_race_stopped_ms() < 1000);

  // Motor Izquierdo
  if (motors_enabled) {
    if (velI > 0) {
      // Adelante
      ledcWrite(PWM_MOTOR_LEFT_A, PWM_MOTORS_MAX);
      ledcWrite(PWM_MOTOR_LEFT_B, PWM_MOTORS_MAX - (PWM_MOTORS_MAX * velI / 100));
    } else if (velI < 0) {
      // Reversa
      ledcWrite(PWM_MOTOR_LEFT_A, PWM_MOTORS_MAX - (PWM_MOTORS_MAX * abs(velI) / 100));
      ledcWrite(PWM_MOTOR_LEFT_B, PWM_MOTORS_MAX);
    } else {
      // Detenido
      ledcWrite(PWM_MOTOR_LEFT_A, PWM_MOTORS_MIN);
      ledcWrite(PWM_MOTOR_LEFT_B, PWM_MOTORS_MIN);
    }
  } else {
    // Motores deshabilitados
    ledcWrite(PWM_MOTOR_LEFT_A, PWM_MOTORS_MIN);
    ledcWrite(PWM_MOTOR_LEFT_B, PWM_MOTORS_MIN);
  }

  // Motor Derecho
  if (motors_enabled) {
    if (velD > 0) {
      // Adelante
      ledcWrite(PWM_MOTOR_RIGHT_A, PWM_MOTORS_MAX);
      ledcWrite(PWM_MOTOR_RIGHT_B, PWM_MOTORS_MAX - (PWM_MOTORS_MAX * velD / 100));
    } else if (velD < 0) {
      // Reversa
      ledcWrite(PWM_MOTOR_RIGHT_A, PWM_MOTORS_MAX - (PWM_MOTORS_MAX * abs(velD) / 100));
      ledcWrite(PWM_MOTOR_RIGHT_B, PWM_MOTORS_MAX);
    } else {
      // Detenido
      ledcWrite(PWM_MOTOR_RIGHT_A, PWM_MOTORS_MIN);
      ledcWrite(PWM_MOTOR_RIGHT_B, PWM_MOTORS_MIN);
    }
  } else {
    // Motores deshabilitados
    ledcWrite(PWM_MOTOR_RIGHT_A, PWM_MOTORS_MIN);
    ledcWrite(PWM_MOTOR_RIGHT_B, PWM_MOTORS_MIN);
  }
}

/**
 * @brief Establece la velocidad de la turbina/succión usando protocolo ESC
 * Protocolo servo: 1000μs = apagado, 2000μs = máximo
 *
 * @param vel Velocidad de la turbina (0-100%)
 */
void set_fan_speed(int vel) {
  vel = constrain(vel, 0, 100);
  if (vel != 0) {
    // Mapear 0-100% a rango 102-204 (1000μs a 2000μs)
    int pwm_value = map(vel, 0, 100, PWM_FAN_MIN, PWM_FAN_MAX);
    ledcWrite(PWM_FAN, pwm_value);
  } else {
    // Apagar turbina
    ledcWrite(PWM_FAN, PWM_FAN_MIN);
  }
}

/**
 * @brief Detiene ambos motores y la turbina
 *
 */
void stop_motors() {
  ledcWrite(PWM_MOTOR_LEFT_A, PWM_MOTORS_MIN);
  ledcWrite(PWM_MOTOR_LEFT_B, PWM_MOTORS_MIN);
  ledcWrite(PWM_MOTOR_RIGHT_A, PWM_MOTORS_MIN);
  ledcWrite(PWM_MOTOR_RIGHT_B, PWM_MOTORS_MIN);
  ledcWrite(PWM_FAN, PWM_FAN_MIN);
}

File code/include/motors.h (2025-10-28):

#ifndef MOTORS_H
#define MOTORS_H

#include <Arduino.h>
#include <pinout.h>

/**
 * @brief Configuración de los motores de tracción
 * Canales: 0 a 3
 * Frecuencia: 5 kHz
 * Resolución: 10 bits
 * Rango: 0 a 1023
 *
 */
#define PWM_MOTOR_LEFT_A 0
#define PWM_MOTOR_LEFT_B 1
#define PWM_MOTOR_RIGHT_A 2
#define PWM_MOTOR_RIGHT_B 3
#define PWM_MOTORS_HZ 5000
#define PWM_MOTORS_RESOLUTION 10
#define PWM_MOTORS_MAX 1023
#define PWM_MOTORS_MIN 0

/**
 * @brief Configuración del ESC de la turbina/succión
 * Canal: 4
 * Frecuencia: 50 Hz (protocolo servo/ESC)
 * Resolución: 11 bits
 * Rango: 102 a 204 (1000μs a 2000μs del protocolo servo)
 *
 */
#define PWM_FAN 4
#define PWM_FAN_HZ 50
#define PWM_FAN_RESOLUTION 11
#define PWM_FAN_MAX 204      // 2000μs (máxima velocidad)
#define PWM_FAN_MIN 102      // 1000μs (apagado/mínimo)

void init_motors();
void set_motors_speed(float velI, float velD);
void set_fan_speed(int vel);
void stop_motors();

#endif // MOTORS_H

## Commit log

2025-10-27 Add lock file for MT Blade PCB design to prevent concurrent edits
    [MT Blade.kicad_pcb]
2025-10-27 Add lock file for MT Blade schematic with hostname and username
    [BTN_SMD_3x6x2.5mm.step, Crystal_SMD_5032-2pin_5.0x3.2mm.step, ESP32-C3 supermini v5.step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]
2025-10-28 Remove 'alta velocidad' from project description

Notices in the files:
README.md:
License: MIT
